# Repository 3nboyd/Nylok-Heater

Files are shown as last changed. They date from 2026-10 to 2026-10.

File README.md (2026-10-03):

# Nylok Handheld Induction Heater Controller




A KiCad reconstruction of a two-mode handheld induction-heater controller concept, prepared for the Notre Dame / Marmon / Nylok Innovate-a-thon.

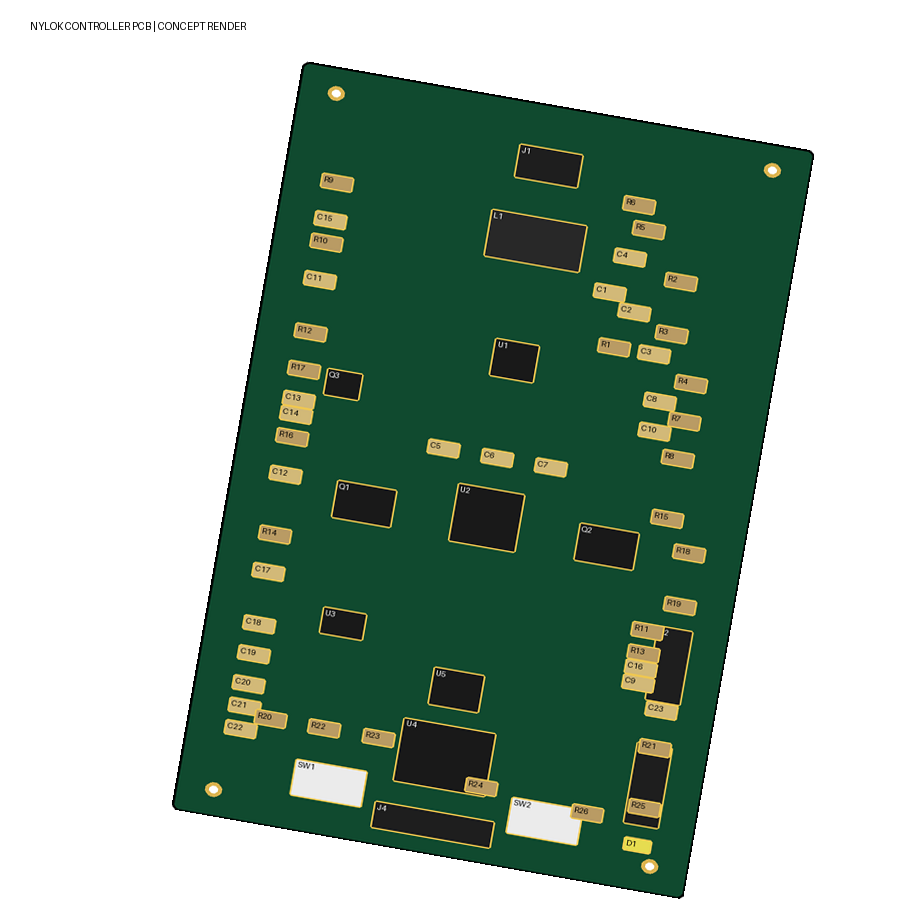
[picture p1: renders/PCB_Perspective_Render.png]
Nylok heater controller PCB concept render


> [!CAUTION]
> **Concept only. Do not fabricate or energize this board.** This preliminary design has not completed electrical review and is not approved for fabrication.

## Overview

The concept uses two protected 18650 cells in series to power a controller board that:

- measures input current;
- provides regulated 5 V and 3.3 V rails;
- controls a switched DC output for an **external ZVS induction driver**;
- exposes an I2C display connector; and
- provides an SWD programming header for the STM32 controller.

The work coil connects to the external ZVS driver, not directly to connector J2 or the battery.

## Current maturity

| Area | Status |
|---|---|
| System concept and sizing study | Documented |
| Logical net map and BOM | Draft |
| Schematic capture | Legacy conceptual reconstruction |
| PCB placement/routing | Visual concept |
| Firmware | Not included |
| Prototype testing | Not performed |
| Fabrication release | **Not approved** |

## Repository contents

```text
.
├── hardware/   KiCad project, schematic, PCB, BOM, and logical net map
├── docs/       Engineering study and connection diagram
├── fab/        Fabrication-readiness notes (not production outputs)
├── renders/    Board concept views
└── scripts/    Repository package checks
```

Key files:

- [`hardware/Nylok_Heater.kicad_pro`](hardware/Nylok_Heater.kicad_pro): KiCad project
- [`hardware/Nylok_Heater.sch`](hardware/Nylok_Heater.sch): legacy KiCad schematic
- [`hardware/Nylok_Heater.kicad_pcb`](hardware/Nylok_Heater.kicad_pcb): nominal 38 mm × 100 mm, two-layer PCB concept
- [`hardware/BOM.csv`](hardware/BOM.csv): draft component/value list
- [`hardware/NETS.csv`](hardware/NETS.csv): logical net map
- [`docs/Nylok_Labeled_PCB_and_Connections.png`](docs/Nylok_Labeled_PCB_and_Connections.png): labeled placement and connection diagram
- [`docs/Induction_System_Specification.md`](docs/Induction_System_Specification.md): research, assumptions, calculations, and primary sources

## Open the project

1. Install KiCad 10 or later.
2. Clone the repository:

   ```bash
   git clone https://github.com/3nboyd/Nylok-Heater.git
   cd Nylok-Heater
   ```

3. Open `hardware/Nylok_Heater.kicad_pro`.
4. Allow KiCad to convert the legacy `.sch` file if prompted, but review the resulting diff before committing it.
5. Read [`docs/Induction_System_Specification.md`](docs/Induction_System_Specification.md) before using the design data.

To check the repository package itself:

```bash
python3 scripts/validate_repo.py
```

This script checks file presence, project metadata, BOM/net structure, PCB references, and PNG integrity. It does **not** certify electrical correctness, safety, or fabrication readiness.

## Safety

Induction heating combines high current, resonant switching, strong local heating, rechargeable cells, and potentially hazardous workpiece temperatures. A short circuit, unsuitable component, control fault, inadequate insulation, or incorrect battery protection can cause burns, fire, cell venting, or equipment damage.

Do not build or energize this concept until a qualified engineer has reviewed the power stage, protection, thermal behavior, creepage/clearance, component ratings, coil/tank behavior, enclosure, battery system, and failure modes. Use current-limited isolated laboratory power during early development and appropriate PPE, guarding, instrumentation, and fire precautions.

## Contributing

Improvements are welcome. Please read [`CONTRIBUTING.md`](CONTRIBUTING.md) before opening an issue or pull request. Do not mark the design fabrication-ready without appropriate engineering review and test evidence.

## License

No open-source license has been selected. The repository is public for review and collaboration, but publication alone does not grant permission to copy, modify, manufacture, or redistribute the design. The owner can add an OSI/OSHWA-compatible license later after choosing the intended terms.

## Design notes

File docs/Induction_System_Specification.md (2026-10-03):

# Handheld induction heater: research and engineering model

Prepared for the Notre Dame / Marmon / Nylok Innovate-a-thon, October 3, 2026.

## Recommended development configuration

Develop a **100 W battery-side input prototype for carbon-steel fasteners**, using an existing nominal 18 V tool battery, a documented low-voltage resonant induction driver, an insulated copper work coil, and closed-loop screw-temperature measurement. Use wired laboratory power first. Keep the sleeve application process separate: heat, switch off, withdraw the coil, then place the sleeve.

This is a system architecture and sizing study, not a fabrication-ready schematic or demonstrated heater. The missing piece for exact component selection is the measured loaded coil impedance and achievable power transfer into representative screws. No specific switching transistors, tank capacitor ratings, PCB trace widths, or coil current limits should be signed off from the thermal calculation alone.

The 65°C and 250°C targets used below are illustrative calculation points. They are **not confirmed Nylok application temperatures**. Exact chemistry, allowable overshoot, dwell and transfer time remain unknown. The main base case is a 10 g effective heated steel mass initially at 25°C.

## 1. Existing-system evidence and material choice

Induction Innovations lists solid copper coils on its Mini-Ductor II. Its instructions recommend closely fitting, evenly wound coils with clearance from the workpiece and describe forming 3–4 turns. Its Bearing Buddy product is described as flexible litz wire. These are established construction patterns, not evidence that a small copied coil will match the original driver's performance. [1–3]

| Coil material | Appropriate role | Decision |
|---|---|---|
| Solid copper conductor | Simple formed work coil with replaceable head | First geometry prototype |
| Copper litz wire | Flexible head and reduced high-frequency copper loss when properly specified | Second comparison prototype |
| Copper tube | Higher-current coil with provision for cooling | Consider if solid-wire temperature becomes limiting |
| Ordinary steel wire | High resistance and undesirable heating of the conductor | Do not use for the work coil |
| Rope or ordinary cord | Appearance mockup only | No electrical function |

Litz uses individually insulated strands with a deliberate construction. Ordinary stranded cable is not equivalent. New England Wire identifies operating frequency as an input to strand-gauge and construction selection. [4]

**Starting head geometry, for an 8 mm diameter screw:**

- Four turns of 2 mm diameter copper conductor.
- Insulation build giving approximately 3 mm finished wire diameter, subject to the insulation supplier's actual dimensions and ratings.
- 10 mm clear insulated bore, leaving nominal 1 mm radial clearance to a centered 8 mm screw.
- 3.5 mm axial turn-center pitch, leaving nominal 0.5 mm between adjacent insulated turns.
- Approximately 13.5 mm axial span.
- Short, closely routed outgoing/return leads, keeping the resonant power stage near the head.
- Ceramic positioning/support pieces and a guard that does not introduce an uncharacterized conductive loop near the coil.

Use purpose-rated high-temperature electrical insulation, such as a qualified glass-fiber/ceramic sleeve system. Specify dielectric strength, temperature, abrasion and chemical resistance. Do not substitute ordinary tape. Manufacturer coil guidance establishes the need for insulation and clearance; it does not establish an exact insulation recipe for our head. [2]

The copper coil can heat through its own electrical loss and through radiation from the screw. Induction does not mean the coil stays cold. Test short repeated bursts and measure coil temperature before claiming an operating duty cycle.

## 2. Physics of induction

Battery DC powers a high-frequency inverter. Alternating current in the copper coil creates a changing magnetic field. That field induces circulating eddy currents in the screw; electrical resistance converts their energy into heat. Ferromagnetic material can also exhibit hysteresis losses. A steady DC coil produces no sustained induction heating after the transient.

The first-principles relationships are:

\[\oint E\cdot dl=-d\Phi_B/dt\]

\[J=\sigma E,\qquad p=J\cdot E=J^2/\sigma\]

The workpiece behaves like a lossy, coupled secondary. Coil-to-part coupling and reflected resistance depend on geometry, material and frequency. A short screw differs considerably from a cooking pan or a bolt-removal tool, so their published efficiencies cannot be copied into this project. ST AN4713 explains the resonant coil/load architecture and frequency-dependent power regulation. [5]

**Starting frequency investigation:** approximately 100–200 kHz, as a design-search range rather than a selected frequency. The suitable value depends on loaded inductance, workpiece resistance, coil loss and driver switching loss.

### Skin depth

\[\delta=\sqrt{\rho/(\pi f\mu_0\mu_r)}\]

Illustrative material inputs at 100 kHz:

| Material assumptions | Calculated skin depth |
|---|---:|
| Copper: resistivity 1.72e−8 Ωm, relative permeability 1 | 0.209 mm |
| Example magnetic steel: resistivity 1.5e−7 Ωm, relative permeability 100 | 0.0616 mm |
| Example nonmagnetic stainless: resistivity 7e−7 Ωm, relative permeability 1 | 1.33 mm |

These resistivities/permeabilities are illustrative screening inputs, not measured values for the challenge's screws. Steel permeability changes with field, grade, frequency and temperature. At 200 kHz, these depths decrease by a factor of square-root two.

Skin depth identifies where current concentrates initially. **Do not budget heat only for this thin skin.** Heat conducts into the body while the heater runs and after it stops.

### Coil field, inductance and resonance

A long-solenoid screening relationship is:

\[B\approx\mu_0NI/\ell\]

Our short coil requires an end correction and a workpiece model. Increasing turns or current changes field, but it also changes inductance, copper loss and driver loading. It does not provide a universal power formula.

An unloaded long-solenoid approximation gives:

\[L\approx\mu_0N^2 A_{coil}/\ell\]

For four turns, mean conductor radius about 6.5 mm and length about 13.5 mm, this gives approximately **0.20 µH**. This short-coil approximation is crude. Lead inductance, finite geometry and the inserted steel can materially change the value. Measure both unloaded and loaded impedance at the intended frequency.

\[f_0=1/(2\pi\sqrt{LC})\]

If measured effective L were 0.20 µH, resonance would require about 12.7 µF at 100 kHz or 3.17 µF at 200 kHz. These are arithmetic examples, **not capacitor selections**. Resonant RMS current, reactive voltage, temperature, ESR and topology determine capacitor-bank construction and rating. Low DC supply voltage does not imply low resonant stress.

Circulating coil current can be much larger than battery current. For example, a 100 W input draws about 5.6 A at nominal 18 V, while a tank might circulate tens of amperes. The latter must be established by measurement and circuit analysis. At an illustrative 40 A RMS and 3 mΩ AC coil resistance, copper loss is 4.8 W. Skin/proximity effects and warm copper can increase resistance.

## 3. Coil coverage and actual thermal mass

For N turns, center pitch p and finished wire diameter D:

\[L_{span}=(N-1)p+D\]

For the proposed geometry, Lspan = 13.5 mm. The cylindrical envelope opposite an 8 mm screw is:

\[A_{band}=\pi dL_{span}=339\text{ mm}^2\]

This is a geometric reference area. The coil has **zero intended contact area with the screw**. Magnetic fields overlap between turns and extend beyond the head. Copper-wire thickness does not carve a sharply bounded heated band.

A solid cylindrical segment of that length and diameter has volume679 mm³ and, at an assumed steel density7.85 g/cm³, mass5.33 g. Actual threaded volume differs. At cp0.5 J/g/K, heating this segment from25°C to250°C would require about600 J if thermally isolated.

It is not thermally isolated. The rest of the screw, head and holder absorb heat. The base system model therefore uses10 g effective mass. We must calibrate that against temperature measurements near and away from the coil.

For an illustrative carbon-steel thermal diffusivity1.2e−5 m²/s, the diffusion length scale sqrt(alpha*t) is about17 mm over24 seconds. This is a scale estimate, not a sharp boundary or validated temperature profile. Nonuniform initial heating and colder adjacent metal can shorten the sleeve-placement window considerably.

The sleeve/stencil defines **coating location**. The heater prepares a region that may be wider. A1–2 thread coating band does not require a1–2 thread electromagnetic footprint.

## 4. Thermal model with external factors

The supplied calculator numerically integrates:

\[mc\,dT/dt=(P_{battery}-P_{controls})\eta_{conversion}\eta_{coupling}-hA(T-T_a)-\epsilon\sigma_{SB}A(T_K^4-T_{a,K}^4)-G(T-T_a)\]

| Input | Base assumption | Meaning |
|---|---:|---|
| Effective heated mass |10 g| Not necessarily the full fastener mass |
| Specific heat |0.5 J/g/K| Constant screening approximation |
| Ambient / target |25°C /250°C| Illustrative temperatures |
| Battery-side power |100 W| Includes controls |
| Controls |1 W| Also consumed between shots |
| Conversion efficiency |90%| Combined electrical-conversion assumption |
| Coupling fraction |60%| Electrical output transferred to modeled metal |
| Exposed screw area |12 cm²| Total modeled hot area, not only339mm² band |
| Convection coefficient |25 W/m²/K| Example mild-airflow assumption |
| Emissivity |0.3| Finish-dependent assumption |
| Holder conductance |0.02 W/K| Simplified loss path to an ambient-temperature holder |
| Usable battery fraction |80%| Reserve/aging/cold allowance, separate from conversion |

The model places53.46 W into the metal before environmental/holder losses. At250°C it loses about6.75 W to convection,1.37 W to radiation and4.5 W through the holder. Approximate instantaneous net heating power at that point is40.8 W.

Base sensible heat is1,125 J. The numerical model adds about153 J of external/holder loss during heating, reaches the target in23.9s and draws about0.664 Wh for that heating cycle.

### Predicted scenarios

| Scenario | Calculated time | Total cycle energy |
|---|---:|---:|
|5 g effective mass|11.6s|0.32Wh|
|10 g effective mass|23.9s|0.66Wh|
|30 g effective mass|79.9s|2.22Wh|
|10 g, illustrative65°C target|3.8s|0.11Wh|
|10 g, h raised to75 W/m²/K|28.7s|0.80Wh|
|10 g,0°C ambient and h75|33.5s|0.93Wh|
|10 g, coupling reduced from60% to30%|56.4s|1.57Wh|

Mass comparisons use exposed area proportional to mass^(2/3), a simplified similar-shape comparison. These are not measured times and do not promise uniform temperature. The controller must also deal with sensor lag and overshoot, especially in the short65°C example.

### Model limits

- No coating-specific dwell or reheating is included.
- No sleeve thermal mass or transfer enthalpy is included.
- No evaporation of a wet screw or active rain is included. Wet fasteners require separate treatment.
- No battery-voltage sag model or tank-impedance calculation is included.
- Constant material properties approximate the temperature range.
- A lumped node does not predict along-screw gradients or all surface temperatures.
- The effective holder-loss path must be fitted to actual hardware.
- Repeated coil/electronics temperature rise can impose cooldown time even if battery energy remains.

Use the thermal model for energy and runtime sizing. Use instrumented tests or electromagnetic/thermal simulation for coupling, gradients and heater limits.

## 5. Battery energy, mAh and hours of use

\[E_{rated}(Wh)=V_{nominal}\times mAh/1000\]

An18 V,5,000 mAh pack contains nominal90 Wh. DEWALT identifies its20V MAX* platform as18 V nominal; use nominal voltage in the energy calculation. [6]

At80% usable capacity, the model has72 Wh available. Conversion losses are handled in the heating model and are not subtracted a second time from this capacity allowance.

\[P_{avg}=P_{controls}+R\,E_{incremental\ heating}\]

R is screws/hour; incremental heating energy excludes continuous controls to avoid double counting. For the base screw it is0.658 Wh/screw.

| Base screw usage |Average power|Work time,18V5Ah|Approximate screws/charge|
|---|---:|---:|---:|
|15/hour|10.9W|6.6h|99|
|30/hour|20.7W|3.5h|104|
|60/hour|40.5W|1.8h|107|
|Continuous100W draw|100W|43.2minutes|Not a throughput claim|

Lower-throughput operation wastes more capacity in the continuously powered controls. Sleep/off-between-use can improve that part of the budget. Tool thermal duty must independently support the requested throughput.

At30 screws/hour, the model requires about2.88 Ah at18 V for2h and5.76 Ah for4h. An18 V8 Ah pack would model about5.6h at that throughput. Under the weak-coupling case, a5Ah pack models about1.5h at30/hour. Capacity alone does not establish discharge-current capability.

**Why a510 battery is not the selected source:** the thread standard specifies an interface, not a power rating. A hypothetical3.7 V650mAh battery has only2.4Wh rated energy and would need roughly27A to supply100W before additional losses. This example is not the specification of Noah's actual battery. We need its label, continuous output rating and cutoff behavior before considering it.

### Existing-power routes

1. **Laboratory isolated current-limited DC supply:** first driver and coil measurements. Compatible voltage/current depend on the chosen documented driver.
2. **Tool battery through a manufacturer PD adapter:** DEWALT DCB094 supports up to100W output. Negotiate a supported profile and verify actual100W delivery, startup and overload behavior. [7] Keep the high-frequency tank near the coil, not at the belt-end of a long HF cable.
3. **Direct tool-battery input:** final compact version, only with a compatible interface and implemented pack/tool protection requirements. A plastic slide adapter alone does not establish undervoltage or thermal protection.

For USB-C at20V,100W means5A. Use a5A-rated electronically marked cable and proper PD negotiation. Adapter output power and battery-side input differ due to adapter loss; the100W battery-side base budget can keep tool output below the adapter's ceiling. Do not promise100W to the screw.

## 6. System architecture and future KiCad PCB

Power path: existing battery/interface -> input protection/current sensing -> compatible low-voltage resonant inverter -> tank capacitor bank -> short coil leads -> insulated work coil.

Measurement/control path: insulated screw-contact thermocouple -> conditioning/converter -> MCU -> driver power command; MCU also operates LCD and reads profile knob/trigger. Monitor the work-head/power-stage temperature independently.

### Candidate blocks

|Block|Development choice|Selection condition|
|---|---|---|
|MCU|STM32-class or similarly capable3.3V controller|Enough timers/SPI/ADC, watchdog and documented driver interface|
|Screw sensor|Electrically insulated, small K-type contact junction|Required temperature, response and repeatable surface contact|
|Thermocouple interface|MAX31856 candidate|SPI, cold-junction compensation, fault handling; RF environment verification|
|Display|Small LCD with actual/target/status|Display is not the sensor|
|Selector|Rotary encoder or detented knob|Select coating recipe; do not present voltage as temperature|
|Power stage|Documented low-voltage resonant module initially|100W-class actual input control, intended tiny-coil L/load compatibility|
|Coil connector|Mechanically keyed low-loss high-current connection|Measured tank current, frequency, contact heating and insulation|

MAX31856 is a real thermocouple converter candidate, with line-frequency filtering and fault detection. Its50/60Hz filtering does not guarantee rejection of100–200kHz induction interference. Analog Devices cautions against grounded-tip use. Use an appropriately isolated junction, short twisted sensor leads, physical separation and input filtering. Verify readings with the inverter enabled and disabled; quiet sampling windows may be needed. [8–9]

Do not choose an IR sensor only because it avoids contact. Small shiny threaded surfaces introduce emissivity, reflection and field-of-view problems. Fluke identifies adjustable emissivity as important for metal measurements. [10]

### Control behavior

On power-up, verify head, supply and sensor. Trigger starts a current-limited heating cycle. Near the selected target, reduce power using the driver's documented control scheme. Assert READY only after validated sensing and any required dwell. Shut down on overtemperature, overcurrent, lost sensor, missing/incorrect head or timeout. Display a valid transfer window only after cooling tests support it.

Voltage alone does not set temperature. Use closed-loop temperature control. A resonant driver may regulate through frequency, controlled bursts or bus voltage; the chosen topology determines the allowable method. Do not add arbitrary series PWM to an undocumented self-oscillating board. ST's high-voltage IGBT cooker examples explain principles but are not low-voltage component selections. [5]

Keep resonant high-current loops small, capacitor paths short and sensing separated from switching nodes. Fuse and current-limit settings, MOSFET voltage/current margin, driver deadtime, capacitor RMS rating, conductor/connector sizing and heatsink design require loaded-circuit testing. MCU current limiting alone does not protect fast faults; use appropriate hardware shutdown.

## 7. Tightening knob and interchangeable heads

A closer coil generally improves coupling, but maintain a physical gap. Manufacturer instructions explicitly avoid coil-to-metal contact. [2]

For the first working prototype, use **fixed S/M/L coil heads with a knob that locks the head and centers the workpiece**. This retains a simple adjustment while avoiding continuous unknown retuning.

For a later true diameter-adjusting head, the knob must move an insulated flexible coil through a mechanically limited range, preserve turn count/separation and clearance, and operate only with power off. Test the entire adjustment range with the driver. Changes to coil shape alter L, coupling, resonance and possible circulating current. An automatic impedance/tuning routine or restricted calibrated positions may be required.

Specify usable fastener diameters per head, not only nominal S/M/L labels. For a radial clearance g, clear bore must be at least fastener diameter+2g, plus manufacturing/alignment allowance. Head diameters may exceed shank diameters, requiring an opening coil or insertion from the screw tip. Split coils create another high-frequency connector problem; they are not automatically the simpler option.

Support nonmagnetic screws mechanically. Carbon steel is the initial induction-validation material. Austenitic stainless, brass and aluminum need separate driver/coil tests and may require a different head or another heating method. Do not equate nonmagnetic with electrically nonconductive, or promise universal heating with one recipe.

## 8. Measurements that complete the design

1. Weigh representative screws and record material, plating, diameter, head shape and length.
2. Measure each coil's unloaded/loaded inductance and resistance at intended frequencies, not just with DC or a low-frequency meter.
3. Measure battery-side energy per shot and coil/tank current with suitable equipment.
4. Measure temperature at the center band, both band edges, head and remote shaft.
5. Repeat for head sizes, clearances, ambient conditions and consecutive-shot duty.
6. After shutdown, measure cooling at0.5s intervals during real sleeve positioning. Derive the practical transfer window.
7. Confirm sensor error/lag against an independent reference, including during RF operation.
8. Test final coating transfer and function. A correct heater reading is not proof of coating performance.

Measure effective thermal mass and coupling instead of fitting both arbitrarily: use spatial temperature measurements and energy logging to constrain them. One heating-time measurement cannot uniquely identify all the loss parameters.

## Presentation wording

“An18V5,000mAh battery stores about90Wh. Our illustrative100W model uses about0.66Wh to heat a10g steel screw, including assumed losses. At30 screws per hour, that is about3.5hours per charge. Coil coupling and outdoor conditions will determine the measured result.”

Use the editable one-slide deliverable and calculator. Say **estimated/modelled**, not demonstrated. Do not describe the250°C example as the confirmed product recipe.

## Primary sources

1. Induction Innovations, Mini-Ductor II: https://www.theinductor.com/product/mini-ductor-ii/
2. Induction Innovations, coil usage/clearance: https://www.theinductor.com/blog/how-to-properly-use-induction-heating-coils/
3. Induction Innovations, flexible litz example: https://www.theinductor.com/blog/how-to-get-more-out-of-your-mini-ductor-induction-heater/
4. New England Wire, litz engineering: https://litzwire.com/litz-wire-design-engineering/
5. STMicroelectronics AN4713: https://www.st.com/resource/en/application_note/an4713-induction-cooking--igbts-in-resonant-converters-stmicroelectronics.pdf
6. DEWALT5Ah pack and18V nominal: https://www.dewalt.com/en-us/product/dcb205c/20v-max-5ah-starter-kit
7. DEWALT100W PD adapter: https://www.dewalt.com/en-us/product/dcb094k/20v-max-flexvolt-5-amp-usb-charging-kit
8. Analog Devices MAX31856: https://www.analog.com/en/products/max31856.html
9. Analog Devices grounded-tip guidance: https://ez.analog.com/data_converters/a/documents/c/max31856-faq/DO12495/is-it-possible-to-use-maxim-s-thermocouple-to-digital-converter-with-grounded-thermocouple
10. Fluke emissivity: https://www.flukeprocessinstruments.com/en-us/why-use-pyrometers%3F/emissivity-metals

All unreferenced numerical design inputs above are explicit engineering assumptions or calculations, not supplier specifications. Actual coating temperature, chemistry and allowed carrier residue remain outside the supplied information.

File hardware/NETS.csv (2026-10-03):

Net | Connections
BAT_RAW | J1.1; R1.1; U2.VIN; U3.IN
GND | J1.2; J2.2; J3.5; J4.1; U1.GND; U2.GND; U3.GND; U4.GND; U5.GND; SW1.2; SW2.2; D1.K
HEATER_PLUS | Q1.D; Q2.D; J2.1
SENSE_P | R1.1; U1.IN+
SENSE_N | R1.2; U1.IN-
ISENSE | U1.OUT; U4.PA0
BUCK_SW | U2.SW; L1.1
V5 | L1.2; C12.1; C13.1; C14.1; U3.IN; Q1.S
V3V3 | U3.OUT; U4.VDD; U5.VDD; J3.4; J4.2
SCL | U4.PA9; U5.SCL; J4.3
SDA | U4.PA10; U5.SDA; J4.4
DAC_OUT | U5.VOUT; U2.FB_TRIM
HEATER_EN | U4.PA6; Q3.B
GATE | Q3.C; Q1.G; Q2.G
SW_START | SW1.1; U4.PA1
SW_MODE | SW2.1; U4.PA2
STATUS | U4.PA3; R26.1
SWDIO | J3.1; U4.PA13
SWCLK | J3.2; U4.PA14
NRST | J3.3; U4.NRST

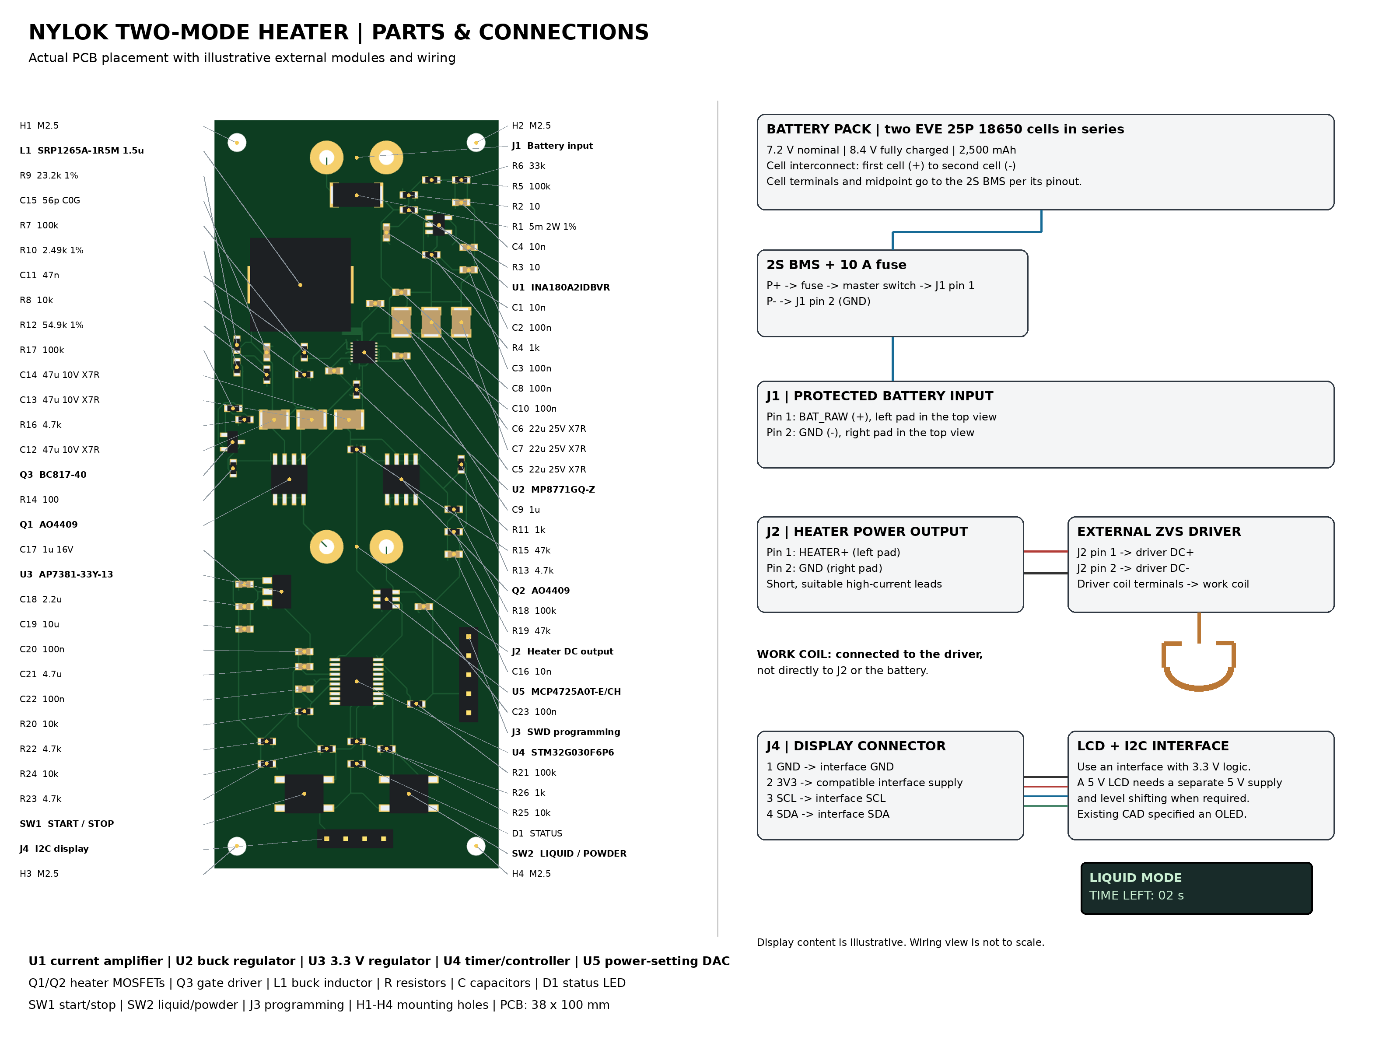
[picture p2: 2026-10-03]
docs/Nylok_Labeled_PCB_and_Connections.png

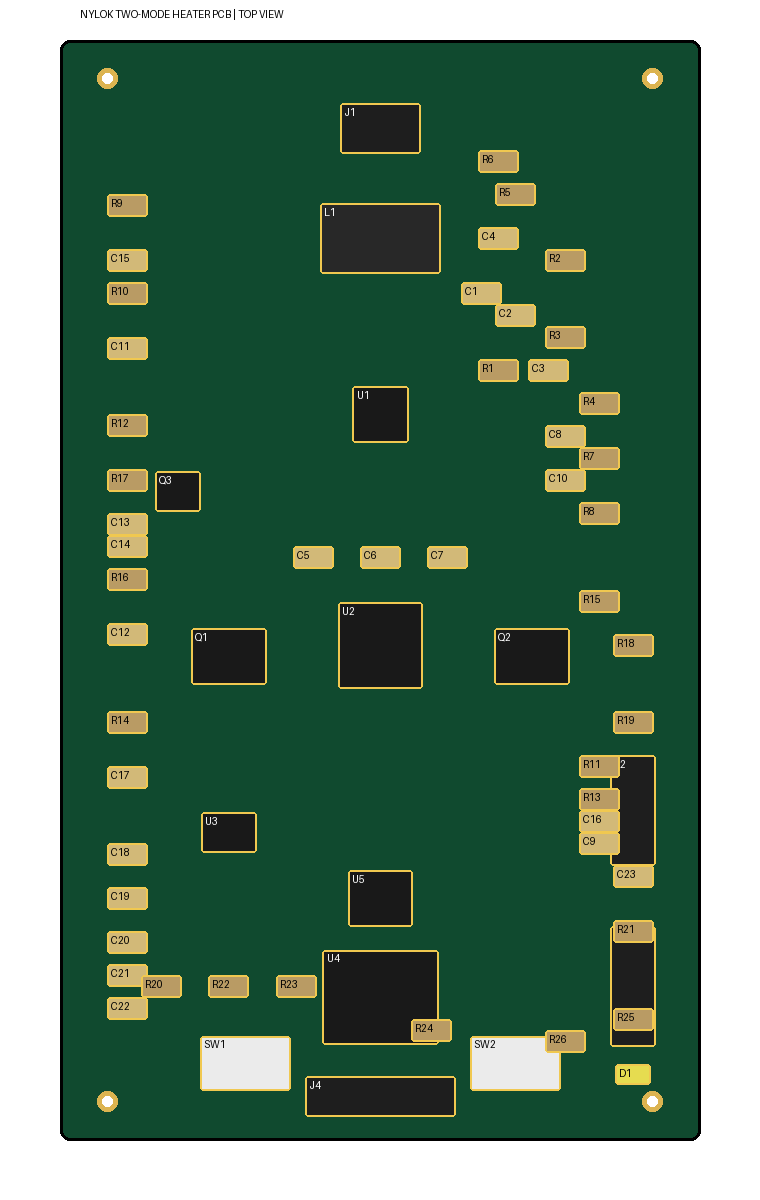
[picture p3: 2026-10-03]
renders/PCB_Top_View.png

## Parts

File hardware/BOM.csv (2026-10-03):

Reference | Symbol/MPN | Value | Footprint | Function
J1 | Conn_01x02 | PROTECTED BATTERY INPUT | Connector_Generic:Conn_01x02 | 2-pin high-current input
J2 | Conn_01x02 | HEATER POWER OUTPUT | Connector_Generic:Conn_01x02 | To external ZVS driver DC input
J3 | Conn_01x05 | SWD PROGRAMMING | Connector_Generic:Conn_01x05 | SWDIO/SWCLK/NRST/3V3/GND
J4 | Conn_01x04 | I2C DISPLAY | Connector_Generic:Conn_01x04 | GND/3V3/SCL/SDA
U1 | INA180A2IDBVR | INA180A2 | Package_TO_SOT_SMD:SOT-23-5 | Current sense amplifier
U2 | MP8771GQ-Z | MP8771 | Package_DFN_QFN:QFN-16-1EP_3x3mm_P0.5mm_EP1.7x1.7mm | Buck regulator
U3 | AP7381-33Y-13 | AP7381-33 | Package_TO_SOT_SMD:SOT-89-3 | 3.3 V regulator
U4 | STM32G030F6P6 | STM32G030F6P6 | Package_SO:TSSOP-20_4.4x6.5mm_P0.65mm | MCU / timer / controller
U5 | MCP4725A0T-E/CH | MCP4725 | Package_TO_SOT_SMD:SOT-23-6 | Power-setting DAC
Q1 | AO4409 | AO4409 | Package_SO:SO-8_3.9x4.9mm_P1.27mm | Heater high-side switch
Q2 | AO4409 | AO4409 | Package_SO:SO-8_3.9x4.9mm_P1.27mm | Heater high-side switch
Q3 | BC817-40 | BC817-40 | Package_TO_SOT_SMD:SOT-23 | Gate driver transistor
L1 | SRP1265A-1R5M | 1.5uH | Inductor_SMD:L_12.5x12.5_H6.5 | Buck inductor
D1 | LED | STATUS | LED_SMD:LED_0603_1608Metric | Status LED
SW1 | SW_Push | START / STOP | Button_Switch_SMD:SW_SPST_TL3301AN | Start/stop button
SW2 | SW_Push | LIQUID / POWDER | Button_Switch_SMD:SW_SPST_TL3301AN | Mode button
R1 | R | 5m 2W 1% | Resistor_SMD:R_2512_6332Metric
R2 | R | 10 | Resistor_SMD:R_0603_1608Metric
R3 | R | 10 | Resistor_SMD:R_0603_1608Metric
R4 | R | 1k | Resistor_SMD:R_0603_1608Metric
R5 | R | 100k | Resistor_SMD:R_0603_1608Metric
R6 | R | 33k | Resistor_SMD:R_0603_1608Metric
R7 | R | 100k | Resistor_SMD:R_0603_1608Metric
R8 | R | 10k | Resistor_SMD:R_0603_1608Metric
R9 | R | 23.2k 1% | Resistor_SMD:R_0603_1608Metric
R10 | R | 2.49k 1% | Resistor_SMD:R_0603_1608Metric
R11 | R | 1k | Resistor_SMD:R_0603_1608Metric
R12 | R | 54.9k 1% | Resistor_SMD:R_0603_1608Metric
R13 | R | 4.7k | Resistor_SMD:R_0603_1608Metric
R14 | R | 100 | Resistor_SMD:R_0603_1608Metric
R15 | R | 47k | Resistor_SMD:R_0603_1608Metric
R16 | R | 4.7k | Resistor_SMD:R_0603_1608Metric
R17 | R | 100k | Resistor_SMD:R_0603_1608Metric
R18 | R | 100k | Resistor_SMD:R_0603_1608Metric
R19 | R | 47k | Resistor_SMD:R_0603_1608Metric
R20 | R | 10k | Resistor_SMD:R_0603_1608Metric
R21 | R | 100k | Resistor_SMD:R_0603_1608Metric
R22 | R | 4.7k | Resistor_SMD:R_0603_1608Metric
R23 | R | 4.7k | Resistor_SMD:R_0603_1608Metric
R24 | R | 10k | Resistor_SMD:R_0603_1608Metric
R25 | R | 10k | Resistor_SMD:R_0603_1608Metric
R26 | R | 1k | Resistor_SMD:R_0603_1608Metric
C1 | C | 10n | Capacitor_SMD:C_0603_1608Metric
C2 | C | 100n | Capacitor_SMD:C_0603_1608Metric
C3 | C | 100n | Capacitor_SMD:C_0603_1608Metric
C4 | C | 10n | Capacitor_SMD:C_0603_1608Metric
C5 | C | 22u 25V X7R | Capacitor_SMD:C_1210_3225Metric
C6 | C | 22u 25V X7R | Capacitor_SMD:C_1210_3225Metric
C7 | C | 22u 25V X7R | Capacitor_SMD:C_1210_3225Metric
C8 | C | 100n | Capacitor_SMD:C_0603_1608Metric
C9 | C | 1u | Capacitor_SMD:C_0603_1608Metric
C10 | C | 100n | Capacitor_SMD:C_0603_1608Metric
C11 | C | 47n | Capacitor_SMD:C_0603_1608Metric
C12 | C | 47u 10V X7R | Capacitor_SMD:C_1210_3225Metric
C13 | C | 47u 10V X7R | Capacitor_SMD:C_1210_3225Metric
C14 | C | 47u 10V X7R | Capacitor_SMD:C_1210_3225Metric
C15 | C | 56p C0G | Capacitor_SMD:C_0603_1608Metric
C16 | C | 10n | Capacitor_SMD:C_0603_1608Metric
C17 | C | 1u 16V | Capacitor_SMD:C_0603_1608Metric
C18 | C | 2.2u | Capacitor_SMD:C_0603_1608Metric
C19 | C | 10u | Capacitor_SMD:C_0603_1608Metric
C20 | C | 100n | Capacitor_SMD:C_0603_1608Metric
C21 | C | 4.7u | Capacitor_SMD:C_0603_1608Metric
C22 | C | 100n | Capacitor_SMD:C_0603_1608Metric
C23 | C | 100n | Capacitor_SMD:C_0603_1608Metric

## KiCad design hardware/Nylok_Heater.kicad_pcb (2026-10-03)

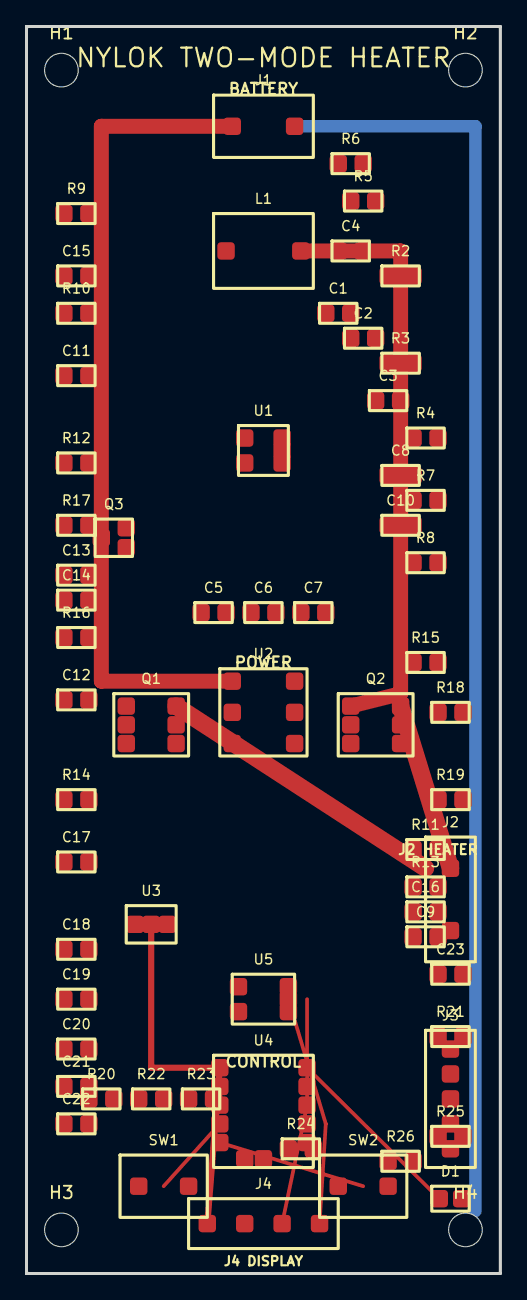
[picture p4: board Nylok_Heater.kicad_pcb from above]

Board: 2 copper layers, 38.0 x 100.0 mm, 68 parts (0 on the bottom side), 20 nets.

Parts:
C1: 10n; C1
C2: 100n; C2
C3: 100n; C3
C4: 10n; C4
C5: 22u 25V X7R; C5
C6: 22u 25V X7R; C6
C7: 22u 25V X7R; C7
C8: 100n; C8
C9: 1u; C9
C10: 100n; C10
C11: 47n; C11
C12: 47u 10V X7R; C12
C13: 47u 10V X7R; C13
C14: 47u 10V X7R; C14
C15: 56p C0G; C15
C16: 10n; C16
C17: 1u 16V; C17
C18: 2.2u; C18
C19: 10u; C19
C20: 100n; C20
C21: 4.7u; C21
C22: 100n; C22
C23: 100n; C23
D1: STATUS; D1
H1, H2, H3, H4: M2.5; MountingHole_2.5mm
J1: BATTERY IN; J1
J2: HEATER OUT; J2
J3: SWD; J3
J4: I2C DISPLAY; J4
L1: 1.5uH; L1
Q1: AO4409; Q1
Q2: AO4409; Q2
Q3: BC817-40; Q3
R2: 10; R2
R3: 10; R3
R4: 1k; R4
R5: 100k; R5
R6: 33k; R6
R7: 100k; R7
R8: 10k; R8
R9: 23.2k 1%; R9
R10: 2.49k 1%; R10
R11: 1k; R11
R12: 54.9k 1%; R12
R13: 4.7k; R13
R14: 100; R14
R15: 47k; R15
R16: 4.7k; R16
R17: 100k; R17
R18: 100k; R18
R19: 47k; R19
R20: 10k; R20
R21: 100k; R21
R22: 4.7k; R22
R23: 4.7k; R23
R24: 10k; R24
R25: 10k; R25
R26: 1k; R26
SW1: START/STOP; SW1
SW2: MODE; SW2
U1: INA180A2; U1
U2: MP8771; U2
U3: AP7381-33; U3
U4: STM32G030F6P6; U4
U5: MCP4725; U5

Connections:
BAT_RAW: J1.1, R5.1, R6.1, R9.1, U2.1
BUCK_SW: L1.1, U2.4
DAC_OUT: C16.1, C17.1, R11.1, R13.1, U2.3, U5.5
GATE: Q1.1, Q2.1, Q3.2, R14.2, R15.1, R18.1
GND: C1.2, C2.2, C3.2, C4.2, C5.2, C6.2, C7.2, C8.2, C9.2, C10.2, C11.2, C12.2, C13.2, C14.2, C15.2, C16.2, C17.2, C18.2, C19.2, C20.2, C21.2, C22.2, C23.2, D1.2, J1.2, J2.2, J3.5, J4.1, Q3.3, R2.2, R3.2, R4.2, R5.2, R7.2, R8.2, R9.2, R10.2, R11.2, R12.2, R13.2, R16.2, R17.2, R18.2, R19.2, R24.2, R26.2, SW1.2, SW2.2, U1.2, U2.2, U2.6, U3.1, U4.2, U5.2
HEATER_EN: Q3.1, R14.1, R16.1, R19.1, U4.7
HEATER_PLUS: J2.1, Q1.4, Q1.5, Q1.6, Q2.4, Q2.5, Q2.6
ISENSE: C11.1, C15.1, R4.1, R6.2, R10.1, U1.1, U4.3
NRST: J3.3, R23.1, R24.1, U4.12
SCL: J4.3, R20.1, U4.8, U5.3
SDA: J4.4, R22.1, U4.9, U5.4
SENSE_N: R2.1, U1.3
SENSE_P: R3.1, U1.4
STATUS: D1.1, R26.1, U4.6
SWCLK: J3.2, R25.1, U4.11
SWDIO: J3.1, R21.1, U4.10
SW_MODE: SW2.1, U4.5
SW_START: SW1.1, U4.4
V3V3: C1.1, C2.1, C3.1, C4.1, C8.1, C9.1, C10.1, C18.1, C19.1, C20.1, C21.1, C22.1, C23.1, J3.4, J4.2, R12.1, R17.1, R20.2, R21.2, R22.2, R23.2, R25.2, U1.5, U3.2, U4.1, U5.1
V5: C5.1, C6.1, C7.1, C12.1, C13.1, C14.1, L1.2, Q1.2, Q1.3, Q2.2, Q2.3, R7.1, R8.1, R15.2, U2.5, U3.3

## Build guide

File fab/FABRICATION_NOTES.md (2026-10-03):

# Fabrication notes

Board outline: 38 mm x 100 mm, nominal 1.6 mm FR-4, 2 copper layers.

This reconstruction is not released for fabrication. Critical items requiring KiCad validation and electrical review include the MP8771 implementation, exact vendor pin mapping, power-stage current path, gate-drive details, shunt Kelvin routing, trace widths, copper weight, thermal relief, EMI, BMS/fuse/master-switch integration, and external ZVS compatibility.

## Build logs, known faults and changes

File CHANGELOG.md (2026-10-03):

# Changelog

All notable repository changes are recorded here.

## 0.1.0-concept, 2026-10-03

- Published the initial KiCad concept reconstruction.
- Added the draft BOM, logical net map, engineering specification, connection diagram, and concept renders.
- Added design-readiness and fabrication guidance.
- Added repository integrity checks and GitHub Actions automation.
- Added contribution and safety-reporting guidance.

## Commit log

2026-10-03 Publish Nylok heater controller concept
    [BOM.csv, NETS.csv, Nylok_Heater.kicad_pcb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]
2026-10-21 Feature heater product design and complete cost analysis
